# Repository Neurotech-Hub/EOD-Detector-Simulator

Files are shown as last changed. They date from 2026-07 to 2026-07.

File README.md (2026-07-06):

# EOD Detector — ngspice Simulation

Simulate the EOD detector front-end in incremental **stages**, from sanity checks through passives and active blocks. Python generates waveforms, runs ngspice in batch CLI mode, parses results, and plots waveforms.

Shared models live in [`circuits/models/`](circuits/models/) (INA333, MCP6561 comparator, …).

## Prerequisites

### ngspice

```bash
brew install ngspice
ngspice -v
```

Or set `NGSPICE` to the full path of the binary if it is not on `PATH`.

### Python

```bash
python3 -m venv .venv
source .venv/bin/activate
pip install -e ".[dev]"
```

## Quick start

List stages:

```bash
python scripts/run_stage.py --list
```

Run the INA333 sanity check (regression baseline):

```bash
python scripts/run_stage.py --stage 00_sanity_ina333
python scripts/run_ina333.py                    # same stage (alias)
python scripts/run_stage.py --stage 00_sanity_ina333 --model ti
```

Run the MCP6561 comparator sanity check:

```bash
python scripts/run_stage.py --stage 00_sanity_mcp6561
```

Run the full KiCad schematic incrementally:

```bash
python scripts/run_stage.py --stage 01_passives --waveform rounded
python scripts/run_stage.py --stage 02_frontend --waveform rounded
python scripts/run_stage.py --stage 03_detector --waveform rounded
```

Outputs: `outputs/stages/<stage_id>/`

### Tuning GUI

Interactive local UI for stage selection, parameter tuning, and dual-axis plots:

```bash
pip install -e ".[dev]"   # includes dash
python scripts/run_gui.py
```

Opens `http://127.0.0.1:8050` with three analysis tabs (Electrodes/ELEC_OUT, ELEC_OUT/COMP_IN, Comparator), overview vs single-pulse zoom, and pulse rate in **kHz** (default 0.5 kHz). The Electrodes tab overlays the commanded stimulus (dashed) against the simulated electrode differential so numerical problems are immediately visible.

### Options

```bash
python scripts/run_stage.py --stage 00_sanity_ina333 --gain 100 --pulse-mv 1.0 --plot plotly
python scripts/run_stage.py --stage 00_sanity_ina333 --waveform rounded --pulse-width-us 200
```

Single-pulse zoom (dual y-axis) is generated automatically for EOD input stages. The GUI always zooms the **first pulse** in the train.

```
outputs/stages/00_sanity_ina333/00_sanity_ina333_pulse1_ideal.png
```

| Flag | Default | Description |
|---|---|---|
| `--stage` | `00_sanity_ina333` | Simulation stage id |
| `--model` | (stage default) | Bench variant: `ideal`, `ti`, or `default` |
| `--gain` | 100 | INA333 gain (sets RG = 100k / (G - 1)) |
| `--pulse-mv` | 1.0 | Peak differential pulse amplitude (mV) |
| `--waveform` | square | Pulse shape: `square` (ideal) or `rounded` (smooth lobes) |
| `--pulse-width-us` | 200 | Total biphasic width for rounded waveform (µs) |
| `--sample-us` | auto | Waveform + `.tran` step (µs): 1 rounded, 10 square |
| `--no-pulse-zoom` | off | Skip single-pulse dual-axis plot (CLI only) |
| `--isi-ms` | 20 | Inter-pulse interval (ms) |
| `--num-pulses` | 4 | Number of pulses in the train |
| `--plot` | matplotlib | `matplotlib` or `plotly` |
| `--duration-ms` | 100 | Simulation duration (ms) |
| `--vref` | stage default | Reference voltage (V); 1.65 for KiCad stages |
| `--vthresh` | 1.85 | Comparator threshold (V) for stage 03 |
| `--vdd` | stage default | Supply voltage (V); 3.3 for KiCad stages |
| `--lf-offset` | off | Add slow sinusoidal differential offset (water artifact) |
| `--lf-offset-mv` | 100 | Peak LF offset amplitude (mV) |
| `--lf-offset-center-hz` | 20 | LF offset center frequency (Hz) |
| `--lf-offset-span-hz` | 10 | Draw f uniformly in [center−span, center+span] |
| `--lf-offset-seed` | (random) | Optional RNG seed for reproducible f and phase |

### Slow LF offset (water recording)

Enable `--lf-offset` to superimpose a slow differential sine on the EOD pulse train. Each run draws frequency in **10–30 Hz** (20 ± 10 by default) and a random phase relative to the first pulse. Use this to validate the input high-pass network in `01_passives`: the differential corner is ~59 Hz (2.35 nF effective coupling into the ~950 kΩ R15/R6 load), so a 20 Hz offset is attenuated to roughly a third at the INA inputs. In **Overview** view you should see large slow swings at the electrodes with a visibly smaller residual at the INA inputs when the filter is working.

```bash
python scripts/run_stage.py --stage 01_passives --waveform rounded --lf-offset --lf-offset-mv 150 --duration-ms 50
```

The tuning GUI exposes the same controls under **Slow water offset (~20 Hz)** in the Waveform section.

### INA input network (stages 01–03)

Tune the symmetric INA333 input passive network. Values are SPICE literals applied to both legs (or the shared differential element). INA gain stays fixed at G=2 (RG = 100k).

| Flag | Default | Component |
|---|---|---|
| `--c-couple` | `4.7n` | Input coupling cap (C2, C3) |
| `--r-series` | `100k` | Series input resistor (R4, R7) |
| `--r-vref` | `10Meg` | VREF bias resistor (R6, R8) |
| `--r-diff` | `1Meg` | Differential input resistor (R15) |
| `--c-diff` | `330p` | Differential input capacitor (C4) |
| `--electrode-mismatch` | `0` | Electrode impedance mismatch (%) — see below |

```bash
python scripts/run_stage.py --stage 01_passives --waveform rounded --c-couple 10n --r-series 47k
```

The tuning GUI shows an **INA input network** panel for stages `01_passives`, `02_frontend`, and `03_detector`. Pair with `--lf-offset` and **Overview** view to validate HPF attenuation of slow water artifacts.

### Electrode impedance mismatch (stages 01–03)

`--electrode-mismatch <pct>` (GUI: **Electrode mismatch (%)** in the INA
input network panel) inserts a per-electrode source resistance between the
stimulus and `ELEC_A`/`ELEC_B`:

- **0 (default):** ideal stiff drive (1 mΩ) — identical to the previous
  behavior.
- **m > 0:** enables the electrode model with nominal Rs = **15 kΩ** (fine
  Ag wire, ~5 mm exposed, fresh water — see
  [ELECTRODES.md](ELECTRODES.md)), split ±m/2 between the two electrodes:
  `R_ELEC_A = 15k·(1 + m/200)`, `R_ELEC_B = 15k·(1 − m/200)`.

This demonstrates the two in-band electrode effects from ELECTRODES.md
within the current differential-stimulus architecture: **amplitude droop**
(Rs against C4 forms a ~16 kHz corner at stock values) and **one-sided
biphasic distortion** (unequal Rs against the C2/R4 vs C3/R7 legs skews the
two lobes). With mismatch on, the dashed "Commanded stimulus (ideal)"
overlay in the Electrodes tab visibly departs from the simulated electrode
differential — physically this time, not numerically.

```bash
python scripts/run_stage.py --stage 01_passives --waveform rounded --pulse-mv 300 --electrode-mismatch 20
```

### Comparator network (stages 02–03)

Tune output coupling and hysteresis between INA output and comparator input.

| Flag | Default | Component |
|---|---|---|
| `--c-out` | `2.2n` | Output coupling cap (C5, VREF–ELEC_OUT) |
| `--r-comp` | `4.7k` | Series resistor ELEC_OUT–COMP_IN (R9) |
| `--r-hyst` | `1Meg` | Hysteresis resistor COMP_IN–TRIGGER (R5, stage 03 only) |

The tuning GUI shows a **Comparator network** panel for `02_frontend` and `03_detector`. R5 only applies to `03_detector` — stage 02 has no comparator, so it does not exist there.

Stage 03's comparator is a **behavioral MCP6561 equivalent** ([`eod_comparator_behavioral.inc`](circuits/stages/includes/eod_comparator_behavioral.inc)): threshold comparison against `VTHRESH`, rail-to-rail push-pull output, and hysteresis produced by the **physical R5/R9 network** exactly as on the board (TRIGGER swing through R5 shifts COMP_IN by ~`VDD·R9/(R9+R5)` ≈ 15 mV at the 4.7k/1Meg defaults). The Microchip vendor macromodel was retired from transient benches — see *Known limitations* below.

## Simulation validation

Every run is validated after ngspice completes; a run only counts as
successful when all checks pass. Otherwise the CLI/GUI reports an explicit
error instead of plotting misleading data.

- ngspice output is scanned for `timestep too small` / aborted-transient
  messages even when the exit code is 0.
- ngspice is killed after a **5-minute timeout** — a convergence-stuck run
  raises a clear error instead of hanging indefinitely.
- The raw file must span the full requested duration, be strictly
  monotonic in time, dense enough to trust, and free of NaN/Inf.
- **Stimulus fidelity:** the differential at the filesource nodes
  (`SRC_A − SRC_B`, upstream of the electrode model) is compared against
  the commanded waveform; any deviation above 1 mV fails the run. The
  filesource is stiff, so deviations indicate solver failure — while
  `ELEC_A/ELEC_B` may legitimately deviate when electrode mismatch is
  enabled.
- The GUI overlays the **commanded stimulus (ideal)** as a dashed trace on
  the Electrodes tab, keeps the previous good result when a run fails, and
  shows amber warnings from the quality checks.

## Board mapping (EOD_Detector_v3-1, value changes only)

Every tunable in this tool maps 1:1 onto a component on the fixed v3-1
topology, so explored values transfer straight back to the PCB:

| Sim parameter / flag | Board designator | Stock value |
|---|---|---|
| `--c-couple` | C2, C3 | 4.7 nF |
| `--r-series` | R4, R7 | 100 kΩ |
| `--r-vref` | R6, R8 | 10 MΩ |
| `--r-diff` | R15 | 1 MΩ |
| `--c-diff` | C4 | 330 pF |
| `--gain` (sets RG) | R3 | 100 kΩ (G = 2) |
| `--c-out` | C5 | 2.2 nF |
| `--r-comp` | R9 | 4.7 kΩ |
| `--r-hyst` | R5 | 1 MΩ |
| `--vthresh` | RV1 wiper (R13 = 5.1 kΩ, R17 = 330 Ω divider) | 1.85 V default |
| `--electrode-mismatch` | (environment: the electrodes/water, not a PCB part) | 0 % (model off) |

The monostable network (R11/C6 pulse width, R14/C9, LEDs) is downstream of
TRIGGER and not simulated.

## Suggested component values (sim-derived)

From deterministic sweeps with 200 µs rounded biphasic pulses at 0.5 kHz
(standard E-series values; all within the fixed v3-1 topology):

| Designator | Stock | Suggestion | Why (measured in sim) |
|---|---|---|---|
| **C4** | 330 pF | **47 pF — do not go lower** | Biggest win. Against the ~166 kΩ differential source impedance (2·R4 ∥ R15), 330 pF puts the low-pass corner at ~3 kHz — inside the EOD band. A 200 µs pulse keeps only 47% of its peak (32% at 100 µs). 47 pF moves the corner to ~20 kHz: 78% / 73% preserved. **Below ~43 pF the front end self-oscillates at ~48 kHz with stock C5** — see [C4_STABILITY.md](C4_STABILITY.md). |
| **R3** | 100 kΩ (G=2) | **51 kΩ (G≈3)** | At VTHRESH = 1.85 V, G=2 needs ≥300 mV pulses to trigger; G=3 detects 200 mV, and 100 mV once C4 = 47 pF. G=5 (RG = 24 kΩ) detects 100 mV even with stock C4 but eats headroom on large pulses. |
| **C2, C3** | 4.7 nF | keep, or **2.2 nF** if slow drift dominates | 2.2 nF halves the 20–30 Hz bleed-through at the INA inputs (16% vs 32% residual) for only ~6% pulse-peak loss. Keep 4.7 nF if drift is not a problem in practice. |
| **R9** | 4.7 kΩ | keep | COMP_IN tracks ELEC_OUT faithfully across the R9 sweep (200 Ω – 4.7 kΩ all converge and trigger cleanly). No measured benefit to changing. |
| **C5** | 2.2 nF | **remove** (or ≤ 470 pF) | 2.2 nF directly loads the INA333 output and forms an under-damped resonance; the front end self-oscillates and TRIGGER chatters continuously — the "stuck on" signature. **Bench-confirmed:** ~80 kHz, ~220 mV pk-pk ring at ELEC_OUT, eliminated by removing C5. Detection is identical without it (C4 + amp bandwidth already band-limit the path); 470 pF C0G is acceptable as EMI insurance. Details: [C4_STABILITY.md](C4_STABILITY.md). |
| **R5** | 1 MΩ | keep | Gives a ~15 mV hysteresis band: exactly one TRIGGER edge per pulse, no chatter, in every test. Going much smaller backfires — at 100 kΩ the R5 loading divides COMP_IN enough to raise the effective threshold and detection stops entirely. |
| **RV1** (VTHRESH) | ~1.85 V | keep as trim | Margin table: at G=3 with C4 = 47 pF, 100 mV pulses clear 1.85 V. Trim down for weaker signals, up to reject noise. |

Caveats, stated plainly:

- These sweeps optimize **pulse fidelity, slow-drift rejection, and
  threshold margin** against the commanded differential stimulus. Resistive
  **electrode impedance mismatch** can now be enabled
  (`--electrode-mismatch`), but **polarization (double-layer C), half-cell
  drift, and common-mode pickup are still not modeled** (see Deferred
  below), so treat those aspects as unverified by simulation.
- Combined check: with 100 mV LF drift superimposed on 300 mV pulse trains,
  both stock and suggested values produce exactly one trigger per pulse
  with zero drift-induced extras.

## Known limitations and sim-only elements

| Element | Physical? | Notes |
|---|---|---|
| Behavioral comparator (stage 03) | Equivalent | Reproduces the MCP6561's threshold, rail-to-rail output, and R5/R9 hysteresis; omits input bias/offset details and exact ~50 ns propagation delay (negligible vs 200–1000 µs EODs). |
| MCP6561 vendor macromodel | Retired for transient | Its ESD clamp diodes collapse the ngspice timestep **non-deterministically** when cascaded with the INA333 macromodel; solver sweeps (`sparse`, `rshunt`, `trap`, `itl4`, `cshunt`) either failed or distorted TRIGGER. Still used in the standalone `00_sanity_mcp6561` stage. |
| `Rload_amp` 1 MΩ (ELEC_OUT–VREF) | Bench load | Stabilizes the INA output in simulation. |
| `Rload_comp` 10 kΩ (TRIGGER–GND) | Bench load | Conventional comparator output load. |
| Ideal `VREF` source | Simplified | OPA333 reference buffer omitted ([stage 03 README](circuits/stages/03_detector/README.md)). |
| Ideal `VTHRESH` source | Simplified | RV1 potentiometer divider replaced by a fixed source (`--vthresh`); keep suggested thresholds within RV1's achievable range. |
| `sim_ti_transient.inc` options | Solver tuning | `method=gear`, relaxed tolerances, `TMAX=10u` for the TI INA333 macromodel. |
| XSPICE `filesource` stimulus | Sim input | Stiff voltage source pair on SRC_A/SRC_B; cannot be loaded by the circuit. `R_ELEC_A/B` (electrode mismatch model) sit between the source and ELEC_A/ELEC_B. |

### Deferred: electrode polarization and common-mode (CM-to-DM) modeling

**Resistive electrode mismatch is now modeled** via
`--electrode-mismatch` / the GUI's Electrode mismatch (%) control (per-
electrode series Rs = 15 kΩ ± m/2 between the source and
`ELEC_A/ELEC_B`). Still deferred: **electrode polarization (double-layer
capacitance), half-cell potential drift, and a separate common-mode /
gradient source for CM-to-DM conversion** — the remaining suspects for the
real-world continuous triggering issue. Design notes for bare Ag vs
Ag/AgCl and what to model next: [ELECTRODES.md](ELECTRODES.md).

### Detector convergence

With the behavioral comparator, the full R9 × pulse-shape matrix (200 Ω to
4.7 kΩ, rounded and square) converges deterministically in seconds — verified
by `pytest -m integration`. Any failure is loud: output scanning, post-run
validation, and a 5-minute ngspice timeout guarantee no silent partial plots.

## Project layout

```
circuits/
├── models/              Shared subcircuits (INA333, MCP6561, …)
└── stages/              Incremental simulation stages
    ├── README.md        Stage progression and how to add stages
    ├── 00_sanity_ina333/   INA333-only regression bench
    ├── 00_sanity_mcp6561/  MCP6561 comparator threshold step
    ├── 01_passives/        Electrode coupling + INA bias network
    ├── 02_frontend/          INA333 (G=2) + output filter
    ├── 03_detector/          Full front-end + behavioral comparator
    ├── includes/             Shared netlist fragments
    └── _template/          Copy to start a new stage

src/eod_sim/
├── stages/registry.py   Stage definitions (register new stages here)
├── runner.py            Shared generate -> simulate -> plot pipeline
├── waveforms.py         EOD pulse train generation
├── ngspice.py           Batch CLI runner and netlist patching
├── results.py           Raw file parsing
└── plot.py              Matplotlib / Plotly plots

scripts/
├── run_stage.py         Main CLI for any stage
└── run_ina333.py        Alias for sanity stage

outputs/stages/<stage_id>/   Generated artifacts (gitignored)
tests/                       Unit tests
```

## Adding a stage

1. Create `circuits/stages/NN_name/` with bench netlist(s) — see [`circuits/stages/_template/`](circuits/stages/_template/)
2. Register in [`src/eod_sim/stages/registry.py`](src/eod_sim/stages/registry.py) with `status="active"`
3. Run: `python scripts/run_stage.py --stage NN_name`

Full checklist: [`circuits/stages/README.md`](circuits/stages/README.md)

## TI vendor model

The TI macromodel is at [`circuits/models/ina333_ti.lib`](circuits/models/ina333_ti.lib). Use `--model ti` on the sanity stage. See [`circuits/models/TI_MODEL.md`](circuits/models/TI_MODEL.md).

## Tests

```bash
pytest                    # fast unit tests
pytest -m integration     # end-to-end ngspice runs (slow; requires ngspice)
```

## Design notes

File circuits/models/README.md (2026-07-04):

# Shared SPICE models

Reusable subcircuits and vendor macromodels for all simulation stages.

| Model | File | Wrapper | Docs |
|---|---|---|---|
| INA333 ideal | [`ina333_ideal.sub`](ina333_ideal.sub) | `INA333_IDEAL` | — |
| INA333 TI | [`ina333_ti.lib`](ina333_ti.lib) | `INA333` | [`TI_MODEL.md`](TI_MODEL.md) |
| MCP6561 comparator | [`mcp6561.lib`](mcp6561.lib) | `MCP6561` | [`MCP6561.md`](MCP6561.md) |

Include from stage netlists with a path relative to the stage folder:

```spice
.include "../../models/mcp6561.lib"
```

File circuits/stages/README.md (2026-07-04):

# Circuit stages

Simulations are organized as numbered **stages** — incremental slices of the real EOD detector schematic.

## Progression

| Stage | Folder | Status | Description |
|---|---|---|---|
| 00 | [`00_sanity_ina333/`](00_sanity_ina333/) | active | INA333 only — regression / sanity check |
| 00 | [`00_sanity_mcp6561/`](00_sanity_mcp6561/) | active | MCP6561 comparator threshold step |
| 01 | [`01_passives/`](01_passives/) | active | Electrode coupling + INA bias network |
| 02 | [`02_frontend/`](02_frontend/) | active | Passives + INA333 (G=2) + output filter |
| 03 | [`03_detector/`](03_detector/) | active | Full front-end + MCP6561 comparator |

Shared netlist fragments: [`includes/`](includes/)

Run any active stage:

```bash
python scripts/run_stage.py --list
python scripts/run_stage.py --stage 01_passives --waveform rounded
python scripts/run_stage.py --stage 02_frontend --waveform rounded
python scripts/run_stage.py --stage 03_detector --waveform rounded
```

Outputs land in `outputs/stages/<stage_id>/`.

## Shared resources

- **`circuits/models/`** — Reusable subcircuits and vendor models (INA333, MCP6561, …). See [`models/README.md`](../models/README.md).
- **`circuits/stages/includes/`** — Shared netlist fragments from KiCad schematic
- **`circuits/stages/_template/`** — Copy to start a new stage

## Adding a stage

1. Create `circuits/stages/NN_name/` with `README.md` and bench netlist(s)
2. Use `.include "../includes/..."` for shared fragments
3. Use `file="input_diff.txt"` in filesource blocks (patched at run time)
4. Add an entry to `src/eod_sim/stages/registry.py`
5. Run and commit

See [`_template/README.md`](_template/README.md) for a checklist.

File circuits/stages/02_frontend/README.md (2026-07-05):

# Stage 02 — INA333 front-end

Full input network plus INA333 (U6, RG = 100 kΩ → G = 2 V/V) and output coupling (C5, R9) to the comparator input node. The hysteresis resistor R5 and the MCP6561 are not populated in this stage — COMP_IN is observed open-circuit (high-impedance), as a scope probe would see it. TRIGGER does not exist here.

## Run

```bash
python scripts/run_stage.py --stage 02_frontend --waveform rounded
python scripts/run_stage.py --stage 02_frontend --model ti --waveform rounded
```

## Expected

- Measured gain at ELEC_OUT ≈ 2 V/V
- Pulse zoom: INA input diff vs ELEC_OUT − VREF

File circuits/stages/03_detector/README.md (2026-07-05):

# Stage 03 — Full detector

Complete KiCad front-end: passives, INA333 (G=2), output filter, and a behavioral MCP6561 comparator equivalent with fixed threshold.

## Simplifications

- OPA333 reference buffer → ideal `VREF = 1.65 V`
- RV1 potentiometer divider (R13/R17) → fixed `VTHRESH = 1.85 V` (tune with `--vthresh`)
- MCP6561 → behavioral comparator (`eod_comparator_behavioral.inc`): threshold comparison, rail-to-rail push-pull output, and hysteresis from the physical R5/R9 network

## Run

```bash
python scripts/run_stage.py --stage 03_detector --waveform rounded
python scripts/run_stage.py --stage 03_detector --model ti --waveform rounded
python scripts/run_stage.py --stage 03_detector --waveform rounded --vthresh 1.70 --pulse-mv 50
```

## Benches

Both variants use the behavioral comparator (`eod_comparator_behavioral.inc`) and converge deterministically:

- `ideal` — ideal INA333 model
- `ti` — TI INA333 vendor macromodel with relaxed transient options (`sim_ti_transient.inc`)

The Microchip MCP6561 macromodel was **retired from these benches**: its ESD clamp diodes collapsed the ngspice timestep non-deterministically when cascaded with the INA333 macromodel (see [MCP6561.md](../../models/MCP6561.md)). Hysteresis behavior is unchanged — it comes from the physical R5/R9 network, which is fully modeled.

## Notes

With G=2, a 1 mV EOD produces ~2 mV at ELEC_OUT. The default threshold (1.85 V) is ~200 mV above the 1.65 V reference — a 1 mV pulse will **not** trigger the comparator. Increase `--pulse-mv` or lower `--vthresh` to explore detection.

## Expected

- Comparator output toggles between ~0 V and ~3.3 V when COMP_IN crosses VTHRESH

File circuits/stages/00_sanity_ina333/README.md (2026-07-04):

# Stage 00 — INA333 sanity check

Baseline test bench: INA333 only, EOD-like differential pulse input, no additional passives.

Use this stage to verify ngspice, waveform generation, and gain after any toolchain or model changes.

## Benches

| File | Model |
|---|---|
| `bench_ideal.cir` | Ideal 3-op-amp INA333 |
| `bench_ti.cir` | TI macromodel (`circuits/models/ina333_ti.lib`) |

## Run

```bash
python scripts/run_stage.py --stage 00_sanity_ina333
python scripts/run_ina333.py                    # same stage (alias)
python scripts/run_stage.py --stage 00_sanity_ina333 --model ti
```

## Expected

At gain=100 and 1 mV differential pulses, measured gain should be ~100 V/V (ideal) or ~101 V/V (TI).

## Outputs

| Artifact | Description |
|---|---|
| `00_sanity_ina333_waveforms_<bench>.png` | Full train overview |
| `00_sanity_ina333_pulse1_<bench>.png` | Single-pulse zoom: Vin diff (left) vs Vout−REF (right) |

Use `--waveform rounded --sample-us 1` for analog dynamics. Adjust zoom with `--pulse-index` and `--pulse-margin-us`.

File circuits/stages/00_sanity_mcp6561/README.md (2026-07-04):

# Stage 00 — MCP6561 sanity check

Comparator threshold crossing with a PWL step on IN+ against a fixed 2.5 V reference on IN-.

## Expected behavior

| Time | IN+ | IN- | OUT (5 V supply) |
|---|-----|-----|---|
| < 1 ms | 1.0 V | 2.5 V | Low (~0 V) |
| > 1 ms | 3.0 V | 2.5 V | High (~5 V) |

## Run

```bash
python scripts/run_stage.py --stage 00_sanity_mcp6561
```

## Model

Uses [`circuits/models/mcp6561.lib`](../../models/mcp6561.lib). Connect VDD to top-level node `3` (ngspice vendor-model quirk — see [`MCP6561.md`](../../models/MCP6561.md)).

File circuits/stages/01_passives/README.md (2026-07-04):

# Stage 01 — Input passives

Electrode coupling (4.7 nF + 100 kΩ), INA bias resistors (10 MΩ to VREF), and differential network (R15, C4).

No active devices — validates HPF response and DC bias at INA inputs.

## Run

```bash
python scripts/run_stage.py --stage 01_passives --waveform rounded
```

## Expected

- INA+ / INA− DC bias ≈ 1.65 V (VREF)
- Differential pulse appears at INA inputs after coupling caps charge
- Overview: electrode diff (top) vs INA input diff (bottom)

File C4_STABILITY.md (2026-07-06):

# C4 stability sweep — front-end oscillation below ~43 pF

**TL;DR:** With the stock output network (C5 = 2.2 nF), the TI INA333 front
end becomes a self-sustaining **~48 kHz oscillator** when C4 drops below
~40 pF. The boundary is sharp (43 pF clean / 39 pF oscillates), it does
**not** require the comparator, and once started it never stops — TRIGGER
chatters rail-to-rail at ~47 kHz indefinitely, which at the monostable/LED
looks exactly like **"comparator stuck on."** Reducing **C5 to ≤ 1 nF
(470 pF recommended)** removes the oscillation entirely and makes C4 a free
choice. Keep **C4 = 47 pF** per the README recommendation, but treat it as
sitting at the edge of the stability region, not just a bandwidth choice.

Context: observed as "strong ringing" in the simulator for C4 < 47 pF, and suspected as a contributor to the continuous-trigger behavior seen in the tank. All sweeps: 300 mV rounded biphasic pulses (200 µs), 0.5 kHz, 4 pulses over 20 ms, stock values unless noted, TI bench.

## Symptom and evidence

From the run that prompted this (stage 03 TI, C4 = 22 pF, otherwise stock):

- First TRIGGER edge at 5.016 ms (first pulse), then **677 rising edges**
at a steady ~~47/ms until the end of the simulation — long after the last
pulse (~~11 ms). Self-sustaining, not per-pulse ringing.
- In a stimulus-free window (15–16 ms): `INA_P`/`INA_N` flat to **0.03 mV**,
while `ELEC_OUT`/`COMP_IN` swing **~0.77 V pk-pk at 47.5 kHz** and
TRIGGER swings rail-to-rail.
- The waveform is smooth over 10–20 solver points per cycle; where the
circuit is not oscillating the baseline is quiet to nanovolts.

**Not a solver artifact.** The oscillating stage-02 case (C4 = 33 pF) was
re-run with strict settings (`trtol=1 reltol=1e-4 abstol=1e-10 method=trap`,
61k timepoints) in place of the relaxed TI options: identical behavior
(0.88 V pk-pk at 48 kHz).

## Sweep results

### C4 boundary (stage 03 TI, C5 = 2.2 nF, R5 = 1 MΩ, rounded pulses)

| C4 | Gain 2 | Gain 3 |
| --- | --- | --- |
| 330 pF (stock) | clean (4 edges) | clean |
| 100 pF | clean | clean |
| 68 pF | clean | clean |
| **47 pF** | **clean** | **clean**  |
| **43 pF** | **clean** | — |
| **39 pF** | **oscillates** (~48 kHz) | — |
| 33 pF | oscillates | oscillates |
| 22 pF | oscillates | oscillates |
| 10 pF | oscillates | oscillates |

The boundary (between 43 and 39 pF) is essentially independent of gain.

### Controls — what the oscillator is and isn't

| Experiment | Result | Conclusion |
| --- | --- | --- |
| Stage 03 **ideal** bench, C4 = 22 pF / 10 pF | clean | The ideal INA (pure gain block) never oscillates → the TI INA333 macromodel's dynamics are the resonant element.  |
| Stage 02 (**no comparator**), C4 = 39/33/22 pF | sustained ~754 mV pk-pk at ELEC_OUT | The comparator is **not required** — the INA + C5 output load self-oscillates. The comparator only reports it. |
| Stage 02, C4 = 330 pF | 3.3 mV ring decaying to 0.05 mV after each pulse | The under-damped resonance exists at stock values too; large C4 keeps it damped. |
| Stage 03 TI, C4 = 22 pF, R5 = 470k/330k/220k | all oscillate | More hysteresis does **not** fix it (consistent with the comparator not being in the loop). |
| **Square** pulses, gain 2 | 100 pF clean; **68 pF and 47 pF oscillate** | Faster edges shift the boundary up — the margin at 47 pF depends on the input being band-limited (real EODs are). |

### Mitigation — C5 (stage 03 TI, C4 = 22 pF, rounded)

| C5 | Result |
| --- | --- |
| 2.2 nF (stock) | oscillates (~48 kHz) |
| **1 nF** | **clean** |
| **470 pF** | **clean** |
| 220 pF | clean |
| 100 pF | clean |

With C5 = 470 pF the front end is clean for **every C4 tested down to
4.7 pF** (gain 3), and the recommended combo passes even the square-pulse
stress test:

| Configuration (gain 3) | Result |
| --- | --- |
| Stock: C4 = 330 pF, C5 = 2.2 nF | clean, measured gain 3.00 |
| README rec: C4 = 47 pF, C5 = 2.2 nF | clean, gain 3.01 |
| **Combo: C4 = 47 pF, C5 = 470 pF**  | **clean, gain 3.00 — clean on square pulses too** |

## Mechanism (what the data supports)

- The INA333 is a 350 kHz-GBW, ~0.16 V/µs micro-power amplifier whose
closed-loop output impedance rises with frequency. **C5 = 2.2 nF sits
directly on its output** (to VREF), forming an under-damped resonance in
the tens-of-kHz range — visible as a small decaying ring even at stock
values. Real amplifiers of this class genuinely misbehave with nF-scale
direct capacitive loads.
- C4 (against the ~166 kΩ differential source impedance, 2·R4 ∥ R15)
band-limits what reaches the amplifier. Below ~40 pF the amplified pulse
edge is fast enough to drive the output stage into a large-signal,
slew-limited oscillation against C5 that never damps out.
- The oscillation loop is confined to the amplifier + its output load: the
INA inputs stay flat while it runs, the ideal-INA bench is immune, and
removing the comparator changes nothing.

## Bench confirmation (Jul 2026)

The predicted oscillation was observed directly on hardware: with
C5 = 2.2 nF and R9 = 10 kΩ (R5 = 1 MΩ), ELEC_OUT showed a sustained
**~80 kHz, ~220 mV pk-pk ring**; **removing C5 eliminated it entirely.**
This is the mechanism above, not the comparator — the sim reproduces the
oscillation in stage 02 with no comparator populated at all. The
frequency shift (sim ~48 kHz → bench ~80 kHz) is expected per the caveats:
the resonance is set by the real part's closed-loop output impedance,
which the TI macromodel only approximates.

Note that **R9 does not protect the amplifier**: C5 is a *shunt* from
ELEC_OUT to VREF, directly on U6's output, upstream of R9. Raising R9
changes the hysteresis divider but leaves the amp facing the full C5.

Follow-up sims with **C5 removed** (open) at R9 = 10 kΩ: detection is
identical to C5 = 470 pF in every case tested — 4 clean TRIGGER edges for
rounded and square 300 mV pulses and for near-threshold 120 mV pulses.
C5 contributes nothing measurable to detection; the signal is already
band-limited by C4 (~20 kHz) and the INA's closed-loop bandwidth
(~115 kHz at G = 3), and chatter immunity comes from the R5/R9
hysteresis, not from C5. **Revised recommendation: delete C5, or keep at
most 470 pF (C0G) as EMI insurance.**

## Tank relevance ("comparator stuck on")

Bench tests with **C4 absent** (populated footprint, no cap) reproduced the
same ringing / stuck-on behavior. In the GUI, **Component defaults →
Detector v3 - No C4** models this with C4 = 1 fF (effectively open between
INA+ and INA−); all other values match the KiCad v3 stock network.

A TRIGGER pin oscillating at ~47 kHz continuously retriggers the
monostable and looks exactly like a stuck-on detector. Two reasons the real
board may be **more** susceptible than the sim:

1. **VREF is ideal in simulation.** On the PCB, C5's resonant current is
  dumped into the OPA333 VREF buffer; VREF bounce couples into the input
   bias network (R6/R8), the INA REF pin, and the RV1 threshold divider —
   feedback paths the sim does not represent.
2. **Electrode source impedance** (now modeled via `--electrode-mismatch`)
  raises the differential source impedance and shifts the input corner,
   moving the effective boundary around in the field.

## Recommendations

1. **Never go below C4 = 47 pF** with the stock output network. The
  simulated boundary is 43→39 pF for rounded 200 µs pulses, and moves up
   to ~68–100 pF for fast-edged (square) inputs — 47 pF has thin margin.
2. **Delete C5, or keep at most 470 pF (C0G).** Bench-confirmed: removing
   C5 eliminates the oscillation, and sims show detection is identical
   with C5 open vs 470 pF (rounded, square, and near-threshold pulses).
   Its intended filtering is redundant (C4 + amp bandwidth already
   band-limit the path) and it sits on the wrong side of R9 to protect
   COMP_IN. Never populate nF-scale values here.
3. Recommended combo, superseding the "keep C5" line in the README's
   suggested-values table: **gain ≈ 3 (R3 = 51 kΩ), C4 = 47 pF,
   C5 removed (or ≤ 470 pF)**, R5/R9 stock. R5 is not a lever here —
   extra hysteresis does not stop the oscillation. R9 stays regardless:
   it forms the hysteresis divider with R5.
4. **Bench verification:** done — see *Bench confirmation* above. A
   series isolation resistor between U6's output and the C5 position
   remains the topology-level fix on a future board revision if a cap is
   ever wanted there.

## Caveats

- The exact boundary values come from the **TI INA333 macromodel**; its
output-impedance model sets the resonant frequency and damping, so trust
the mechanism and the ordering, not the picofarad. The qualitative
warning (nF-scale direct output load + wide input bandwidth =
under-damped front end) is consistent with known amplifier behavior.
- The behavioral comparator faithfully relays the oscillation but plays no
role in creating it (verified in stage 02).
- Sweeps used the stiff electrode drive. Electrode impedance
(`--electrode-mismatch`) adds source resistance that interacts with the
same corner — re-check margin when exploring electrode effects.

See also: [README](README.md) (suggested component values),
[ELECTRODES.md](ELECTRODES.md).

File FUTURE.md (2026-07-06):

# FUTURE — project intent, hardware review, and where to take it

A knowledge-capture document for the EOD Detector (v3-1): why it exists,
how the current hardware works part-by-part, what this simulation/bench
campaign taught us, and what would make the circuit more robust — biased
strongly toward **zero-or-minor changes to the existing PCB**.

See also: [README](README.md) (board map, suggested values),
[C4_STABILITY.md](C4_STABILITY.md) (oscillation sweep),
[ELECTRODES.md](ELECTRODES.md) (electrode physics).

## 1. Project intent

Detect the electric organ discharges (EODs) of weakly electric fish in
fresh water and emit a clean digital TRIGGER (plus LED indication) per
pulse. The device is a **battery-powered wearable**: fine silver wire
electrodes (~5 mm exposed, ~1 cm from the PCB) pick up the fish's
biphasic field pulses — roughly 100 µV to hundreds of mV differential,
200–1000 µs wide, at rates up to ~1 kHz — in an electrically hostile
environment (electrode drift, tank gradients, mains pickup).

The design constraints that shaped everything:

- **Micropower.** Every active part is chosen for µA-class quiescent
  current (INA333 ≈ 25 µA, MCP6561 ≈ 100 µA, OPA333 ≈ 17 µA typical).
  Total analog budget is well under 1 mA — weeks on a small cell.
- **Analog-only detection.** No MCU in the signal path: amplify, filter,
  compare, one-shot. Simple, deterministic, low power.
- **Fixed topology, tunable values.** The v3-1 PCB layout exists; this
  simulation stack exists precisely to find the best *component values*
  within that topology before touching copper.

The simulator's job: faithfully reproduce the physical dynamics of this
chain (validated against tank behavior), so value choices transfer
straight to the board.

## 2. Current hardware (v3-1), component by component

Signal path: electrodes → AC-coupled bias network → INA333 → output
filter → MCP6561 comparator → monostable/LED.

### Mid-rail reference (U1 OPA333 + R1/R2/R10/C19/C20)

| Part | Value | Purpose |
|---|---|---|
| R1, R2 | 1 MΩ each | Divide 3.3 V to 1.65 V mid-rail (only 1.65 µA burned) |
| C19 | 100 nF | Quiets the high-impedance divider node |
| U1 (OPA333) | — | Buffers the divider so VREF can source/sink current |
| R10 | 22 Ω | In the buffer's output/feedback network (per netlist, between VREF and U1−) — helps tolerate the capacitive load on VREF |
| C20 | 100 nF | Local VREF reservoir |

Single-supply operation requires everything to be biased around a
mid-rail "virtual ground." VREF feeds the input bias resistors, the INA
REF pin, C5's cold end, and the threshold divider — **which also makes it
a shared coupling path** (see §4).

### Input coupling and bias (C2/C3, R4/R7, R6/R8, R15, C4)

| Part | Value (stock) | Purpose |
|---|---|---|
| C2, C3 | 4.7 nF | AC-coupling: block electrode DC offset and half-cell drift; with the ~950 kΩ load they form the ~59 Hz differential high-pass |
| R4, R7 | 100 kΩ | Series isolation: limit input current, protect the INA, and (with C4) set the differential low-pass |
| R6, R8 | 10 MΩ | Bias the floating INA inputs to VREF without loading the signal (sets input common mode) |
| R15 | 1 MΩ | Differential termination: defines the differential source impedance seen by the INA (~166 kΩ with 2·R4 ∥ R15) |
| C4 | 330 pF | Differential low-pass with that source impedance; kills RF/EMI **and — as we learned — damps the front end** |

This passive network is the part we spent the campaign testing. Its two
corners bracket the EOD band: high-pass ~59 Hz (drift rejection),
low-pass ~3 kHz at stock C4 (which is actually *inside* the band —
motivating the C4 = 47 pF recommendation that moves it to ~20 kHz).

### Gain stage (U6 INA333 + R3)

R3 = RG sets gain: G = 1 + 100 kΩ/RG. Stock 100 kΩ → G = 2; recommended
51 kΩ → G ≈ 3. The INA333 gives high CMRR at µA supply current, but it's
a 350 kHz-GBW, 0.16 V/µs part — its output stage **cannot drive nF-scale
capacitance** gracefully, which is the root of the instability found in
this campaign.

### Output filter (C5, R9)

| Part | Value (stock) | Purpose |
|---|---|---|
| C5 | 2.2 nF | **Shunt** from ELEC_OUT to VREF — intended as a noise snubber on the comparator path |
| R9 | 4.7 kΩ | Series element into COMP_IN; with R5 sets the hysteresis divider |

C5 sits **directly on the INA output** (upstream of R9, so R9 cannot
isolate the amp from it) — the single most consequential placement on the
board (see §3). Bench + sim verdict: its filtering job is already done by
C4 and the amp's own bandwidth, so it should be deleted or kept ≤ 470 pF.

### Detection (U3 MCP6561, RV1 + R13/R17, R5)

| Part | Value | Purpose |
|---|---|---|
| R13/R17 + RV1 | 5.1 kΩ / 330 Ω + trimmer | Threshold divider: VTHRESH ≈ 1.85 V (~200 mV above VREF), field-adjustable |
| U3 (MCP6561) | — | Push-pull rail-to-rail comparator, ~100 µA |
| R5 | 1 MΩ | Positive feedback COMP_IN←TRIGGER: ~15 mV hysteresis band |

The R5/R9 hysteresis is physically correct on the board and in the sim
(the behavioral comparator model keeps it). ~15 mV gives exactly one
edge per pulse in every clean test; smaller R5 backfires by dividing
COMP_IN down and raising the effective threshold.

### Downstream (not simulated)

Monostable (R11/C6 pulse stretch, R14/C9) and LEDs. These only shape
TRIGGER for visibility; they faithfully relay whatever the comparator
does — including 47 kHz chatter.

## 3. What this build taught us

1. **The front end can self-oscillate, and it looks like "stuck on."**
   With stock C5 = 2.2 nF, dropping C4 below ~40 pF (or removing it —
   the bench condition that reproduced the tank failure) lets the INA
   output ring against C5 in a self-sustaining ~48 kHz oscillation.
   TRIGGER chatters rail-to-rail indefinitely. The comparator is
   innocent; the loop is entirely INA output ↔ C5.
2. **C4 is a stability component, not just a bandwidth trim.** Large C4
   band-limits the edges reaching the amplifier and keeps the resonance
   damped. That's why the board "worked" at 330 pF and failed with C4
   absent.
3. **C5 is not worth keeping — bench-confirmed.** With C5 = 2.2 nF
   (R9 = 10 kΩ) the bench showed a sustained ~80 kHz, ~220 mV pk-pk ring
   at ELEC_OUT; removing C5 eliminated it, matching the sim's predicted
   mechanism (sim frequency ~48 kHz — the difference is the macromodel's
   approximate output impedance). Sims with C5 open are identical to
   470 pF for detection (rounded, square, near-threshold). Its filtering
   is redundant: C4 (~20 kHz) and the INA's closed-loop bandwidth
   (~115 kHz at G = 3) already band-limit the path, and chatter immunity
   comes from R5/R9 hysteresis. Delete it, or keep ≤ 470 pF as EMI
   insurance. R9 stays — it is load-bearing for hysteresis.
4. **Detection margin wants G ≈ 3 and C4 = 47 pF.** At VTHRESH = 1.85 V:
   stock (G=2, C4=330p) needs ≥300 mV pulses; the recommended combo
   detects 100 mV pulses with in-band fidelity preserved (~78% of peak
   at 200 µs vs 47% stock).
5. **Electrodes are a first-class circuit element.** Each wire is
   ~15 kΩ of spreading resistance (Randles cell); *mismatch* between the
   two converts common-mode to differential and skews the biphasic
   lobes. Bare Ag drifts (mV over seconds–minutes); Ag/AgCl mostly fixes
   drift but not mismatch. Now partially modeled
   (`--electrode-mismatch`).
6. **The slow-drift path is under control.** The ~59 Hz input high-pass
   attenuates 20–30 Hz water artifacts to roughly a third at the INA
   inputs; no drift-induced false triggers in any combined test.
7. **VREF is a shared node.** In sim it is ideal; on the board, C5's
   current is dumped into the OPA333 buffer and can bounce the bias
   network, INA REF, and threshold divider together — one plausible
   reason the real board fails *more easily* than the sim.

## 4. Future enhancements

Ordered by invasiveness. Everything in tiers 1–2 uses jellybean 0402/0603
parts (C0G/NP0 ceramics, E24 1% resistors) available from any distributor.

### Tier 0 — value swaps only (do these)

| Change | From → To | Why |
|---|---|-----|
| **C5** | 2.2 nF → **removed** (or ≤ 470 pF C0G) | Bench-confirmed oscillator (80 kHz ring at ELEC_OUT; gone with C5 out). Detection is identical without it — its filtering is redundant. The single highest-value change on the board |
| **R3** | 100 kΩ → **51 kΩ** (G ≈ 3) | Detects 100 mV pulses at the stock threshold; keeps headroom |
| **C4** | 330 pF → **47 pF** (C0G) | Moves the in-band low-pass corner from ~3 kHz to ~20 kHz; preserves pulse fidelity. Safe *once C5 is removed/reduced*; never populate below 47 pF with stock C5, and never leave it off |
| C2, C3 | keep 4.7 nF (or 2.2 nF if drift dominates in practice) | 2.2 nF halves LF bleed-through for ~6% peak loss |
| R5, R9, RV1 | keep | Verified correct as-is; R9 is load-bearing for the R5/R9 hysteresis divider (R9 = 10 kΩ also fine — widens the band to ~33 mV) |

Use C0G/NP0 dielectric for C4 (and C5, if populated) — X7R at these small
values varies with bias and temperature, and C4 sits at a stability
boundary.

### Tier 1 — PCB hacks worth doing on existing boards

- **Series isolation resistor between U6 output and C5** (~100–330 Ω).
  The textbook fix for capacitive loading: it damps the resonance for
  *any* C5. Hack: lift C5's ELEC_OUT pad and bridge with an 0402
  resistor stacked on end. Only relevant if a cap is populated in the C5
  position at all (with C5 removed — the current recommendation — there
  is nothing to isolate). With R9 ≥ 10 kΩ downstream, the divider loss
  at COMP_IN is ≤ 3%.
- **Chloride the electrodes (Ag/AgCl).** Removes the dominant drift
  failure mode for the cost of a bleach dip or anodizing in KCl. Note
  the wearable caveat: thin AgCl layers deplete under sustained bias —
  soak-test before a long deployment.
- **Conformal-coat the input network.** R6/R8 are 10 MΩ; on a wearable
  in water, surface moisture leakage across those nodes rivals the
  intended bias currents. Acrylic or silicone coat over the C2–C4/R4–R8
  region (leave the electrode terminals exposed).
- **Add a scope point on ELEC_OUT** (wire to a via or pad) if not
  already accessible — the definitive stuck-on diagnostic is a
  tens-of-kHz oscillation there.

### Tier 2 — next board spin (same topology, minor edits)

- **Footprint for the U6-output series resistor** (0 Ω default). Free
  insurance, zero layout disruption.
- **Stiffen VREF locally**: bump C20 to 1 µF and verify R10 = 22 Ω
  against the OPA333's capacitive-load tolerance; consider separate RC
  decoupling for the threshold divider branch so comparator-side
  transients don't modulate VTHRESH through the shared node.
- **Tolerance-match the input pairs**: specify C2/C3 at ±5% (C0G) and
  R4/R7 at ±0.1% if available (0402 thin-film 0.1% 100 kΩ is a stocked
  part). Mismatch here converts common-mode to differential exactly like
  electrode mismatch does — it's the half of the CM→DM budget we control.
- **Guard ring or increased clearance** around the INA input nodes
  (10 MΩ bias) to reduce leakage sensitivity.
- **Test pads for electrode impedance measurement** (drive a small
  current, read voltage) so field units can verify electrode health.

### Tier 3 — directions we considered and deliberately deferred

- **MCU/DAC threshold, digital detection.** Contradicts the analog
  micropower intent; RV1 is adequate. Not recommended.
- **Higher-order filtering / active filters.** More op-amps, more µA,
  more instability surface. The passive corners are sufficient once C4
  and C5 are right.
- **Full Randles electrode modeling + common-mode source in sim.**
  Remaining work item (see ELECTRODES.md): per-electrode Rs ∥ (Cdl+Rct),
  drift source, and a CM/gradient source to produce a *tolerance budget*
  for mismatch × pickup. Do this pass before betting a long field
  deployment on threshold margins.
- **New amplifier.** The INA333's capacitive-load sensitivity is real
  but fully managed by C5/isolation-R. Any pin-compatible alternative
  with more drive costs supply current; not worth it.

## 5. Open questions

1. Does the bench show the predicted tens-of-kHz oscillation at U6's
   output during a stuck-on event? (Confirms the mechanism on hardware.)
2. Where does the real stability boundary sit with actual electrodes
   attached? (Electrode Rs interacts with the same input corner — re-run
   the C4 sweep with `--electrode-mismatch` once tank-validated.)
3. How fast do chlorided electrodes deplete in the wearable duty cycle?
   (Bench soak test, not SPICE.)
4. What is the actual CM pickup amplitude in the tank? One measurement
   would anchor the deferred CM→DM simulation pass.

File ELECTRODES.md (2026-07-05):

# Electrodes — notes for sim and bench

Context: fine **silver wire**, ~**5 mm exposed** to water, ~**1 cm** from PCB,
**fresh water** (~50–500 µS/cm). Fixed v3-1 topology; value changes only unless
noted.

## Bare Ag in freshwater (current)

Each electrode behaves roughly like a **Randles cell**:

| Element | Order of magnitude | Relevance at EOD rates (200–1000 µs) |
|---|---|---|
| **Rs** (spreading) | ~3–30 kΩ per wire (~15 kΩ nominal at ~100 µS/cm) | **Dominant** — each electrode ≈ a resistor in-band |
| **Cdl** (double layer) | ~0.5–1 µF | ~200 Ω at ~1 kHz — negligible vs 4.7 nF coupling (C2/C3) |
| **Rct** (charge transfer) | Very high (bare Ag, no stable couple) | Interface drifts; slow polarization |
| **Drift / offset** | Unstable half-cell, mV-scale wander over seconds–minutes | Prime suspect for **LF bleed-through** and **continuous triggering** |

**Rs sits in series with C4 (330 pF)** on the differential path → extra LPF corner
~Rs/(2·C4) ≈ **~16 kHz** with ~30 kΩ total Rs. Compounds the in-band C4 roll-off
already flagged in the README (C4 → **47 pF** recommendation still applies).

**What does *not* matter much:** INA bias current × Rs (~µV); Cdl on the HPF
(dominated by C2/C3).

## What actually drives field failures (bare or chlorided)

1. **Electrode + board mismatch → CM→DM conversion** — unequal Rs/Cdl/Rct, plus
   C2/C3 and R4/R7 tolerance. Tank gradients and mains couple in as
   **common-mode**; even 0.1–1% conversion can produce mV differential at the
   INA — enough to cross threshold intermittently.
2. **Slow drift / DC offset** — large for **bare Ag**; much smaller for **matched
   Ag/AgCl**.

**Now live in the sim:** the stimulus
(`circuits/stages/includes/eod_stimulus.inc`) drives stiff SRC_A/SRC_B
nodes through per-electrode series resistors `R_ELEC_A/B`. The
`--electrode-mismatch <pct>` flag (GUI: **Electrode mismatch (%)**) sets
Rs = **15 kΩ ± m/2** per electrode (0 = stiff drive, model off). This
captures the **resistive** effects above — in-band droop through C4 and
one-sided lobe skew from unequal Rs. Cdl/Rct, drift, and common-mode
pickup are still not represented (see below).

## Ag/AgCl wires — what changes

| | Bare Ag | Ag/AgCl |
|---|---|---|
| **Rct** | Very high | ~1–20 kΩ (reversible AgCl/Ag couple) |
| **Drift / polarization** | Large, unstable | Small stable half-cell (~tens of mV) |
| **Rs, Cdl** | Same (geometry + water) | Same |
| **Mismatch CM→DM** | Yes | **Still yes** — unequal chloriding, area, Rct; board tolerance unchanged |

Ag/AgCl removes the main **drift** failure mode but **not** mismatch or CM→DM.
Residual risk: **differential DC offset** between wires (tens of mV) eating
trigger margin (threshold ~200 mV above VREF at G≈3).

**Wearable caveat:** small chlorided wires **deplete AgCl** under sustained
DC/bias; behavior can revert toward bare Ag over long immersion — bench soak
test, not SPICE.

## Simulation — worth it or not?

- **Not worth chasing exact Rs/Cdl/Rct** — water chemistry and wire prep dominate
  uncertainty.
- **Worth one bounded pass:** mismatch × common-mode **margin** sweep, not “find
  the true Rs.”

**Done (first slice):** per-electrode series **Rs with mismatch %**
(`--electrode-mismatch`) is implemented — see README "Electrode impedance
mismatch."

Remaining for a future pass:

- Replace the differential-only source with **CM source + differential
  (fish) source** and extend each electrode to the full **Rs ∥ (Cdl +
  Rct)** Randles branch with **mismatch %** on Cdl/Rct too.
- **Bare Ag:** include slow drift source (mV, <1 Hz).
- **Ag/AgCl:** low Rct (~5 kΩ), **no large drift**; add small **Vhalf offset
  mismatch** (±25 mV swept).
- Sweep: mismatch 0–50%, CM amplitude; watch INA diff, COMP_IN, TRIGGER for
  false edges.

Output = **tolerance budget**, not a single “correct” electrode value.

## Practical recommendation

1. **Bench:** prefer **Ag/AgCl** (or chlorided silver) for stable LF behavior vs
   bare Ag in plain water.
2. **Component tuning:** proceed with README suggestions (**C4 = 47 pF**, **R3 →
   G≈3**, keep R5/R9/C5) — valid regardless of electrode chemistry for Rs.
3. **Sim next (optional but targeted):** one Ag/AgCl-oriented mismatch + CM sweep
   to confirm margin before long tank tests; skip full bare-Ag drift modeling if
   electrodes are chlorided.

See also: [README](README.md) (board map, suggested values, deferred modeling).

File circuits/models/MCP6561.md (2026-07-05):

# MCP6561 Comparator Model

Microchip rail-to-rail comparator macromodel for ngspice, vendored at [`mcp6561.lib`](mcp6561.lib).

**Source:** Microchip MCP6561 SPICE model (Rev B, 09-Apr-2011)  
**Covers:** MCP6561, MCP6561R, MCP6561U, MCP6562, MCP6564

## Pin order

Subcircuit `MCP6561`:

| Pin | Name |
|-----|---|
| 1 | IN+ (non-inverting) |
| 2 | IN- (inverting) |
| 3 | VDD |
| 4 | VSS |
| 5 | OUT |

Example instance:

```spice
.include "models/mcp6561.lib"
Vsupply 3 0 5
Vref in_n 0 2.5
Vin in_p 0 PWL(0 1.0 1m 1.0 1.001m 3.0 5m 3.0)
XU1 in_p in_n 3 0 out MCP6561
```

## ngspice quirk: VDD node must be named `3`

This vendor model only switches correctly when the **VDD pin connects to a top-level net named `3`**. Using `VDD`, `vsup`, or other supply net names causes the output to stick near 0 V.

Workaround in your netlist:

```spice
Vsupply 3 0 5
XU1 in_p in_n 3 0 out MCP6561
```

Probe other nodes with descriptive names (`in_p`, `in_n`, `out`) as usual.

## ngspice status

Runs in ngspice 46 on transient analysis without file edits. Verified:

```bash
python scripts/run_stage.py --stage 00_sanity_mcp6561
```

Expected: Vout ≈ 0 V when IN+ < IN−, Vout ≈ 5 V when IN+ > IN−.

### Retired from the detector transient benches (stage 03)

This vendor macromodel is **no longer used in the stage 03 detector benches**. Its ESD clamp diodes (`D98`/`D99`, `DESD` with `IS=1e-15`) collapse the ngspice timestep **non-deterministically** when cascaded with the INA333 macromodel — identical runs pass or fail at random with "timestep too small" at `d.xu3.d98`. Exhaustive solver sweeps (`method=gear`/`trap`, `sparse`, `rshunt`, `itl4`, `cshunt`, `TMAX`, parasitic caps) either failed to fix this or distorted TRIGGER (e.g. `cshunt=1p` caused −0.8/+4.1 V rail overshoot).

Stage 03 now uses a **behavioral equivalent** ([`eod_comparator_behavioral.inc`](../stages/includes/eod_comparator_behavioral.inc)): threshold comparison against VTHRESH, rail-to-rail push-pull output referenced to the supply, and hysteresis from the physical R5/R9 feedback network — the electrically relevant behavior for EOD detection, without the stiff ESD network. The vendor includes (`eod_comparator.inc`, `eod_comparator_ti.inc`) remain in the tree, marked deprecated for transient use.

The macromodel is still exercised standalone in the `00_sanity_mcp6561` stage, where it converges fine.

The INA333 TI library may emit harmless `t_abs` warnings on internal resistor models; ngspice ignores them.

## Usage notes (from Microchip)

- Typical performance over −40 °C to +125 °C
- For high-impedance circuits, consider `.options gmin=100f`
- Hysteresis disabled in our vendored copy (`E12` uses `POLY(6)` no-hysteresis line) for reliable ngspice convergence

## Sanity bench

See [`circuits/stages/00_sanity_mcp6561/`](../stages/00_sanity_mcp6561/).

## Updating the model

1. Replace `mcp6561.lib` with a new vendor download
2. Re-apply header comment and hysteresis patch (see top of file)
3. Re-run the sanity stage and confirm the node-`3` VDD workaround still applies

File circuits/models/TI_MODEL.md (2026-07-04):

# TI INA333 SPICE Model

The repo includes an ngspice-compatible copy of the TI macromodel at [`ina333_ti.lib`](ina333_ti.lib).

**Source:** Texas Instruments INA333 TINA-TI Spice Model (SBOM310E / INA333.LIB, Rev 1.2, Feb 2019)

## Usage

```bash
python scripts/run_ina333.py --model ti
python scripts/run_ina333.py --model ideal   # default, faster
```

Compare outputs side by side:

```bash
python scripts/run_ina333.py --model ideal
python scripts/run_ina333.py --model ti
# -> outputs/ina333_waveforms_ideal.png
# -> outputs/ina333_waveforms_ti.png
```

## ngspice patches applied

The vendor file required these changes to run in ngspice:

| Issue | Patch |
|---|---|
| `TEMP` in VOS drift expressions | Fixed at DC (27 °C nominal) |
| PSpice `IF()` | Ternary `? :` operator |
| PSpice `LIMIT()` | Nested ternary clamp |
| PSpice `VSWITCH` | ngspice `SW` (Vt/Vh from VON/VOFF) |

See the header comment in `ina333_ti.lib` for details.

## Pin order

TI subcircuit: `INA333 IN+ IN- VCC VEE OUT REF RG+ RG-`

Bench instance in [`circuits/stages/00_sanity_ina333/bench_ti.cir`](../stages/00_sanity_ina333/bench_ti.cir):

```spice
XU1 in_p in_n VDD 0 out REF RGp RGn INA333
```

## Gain = 1 note

Per TI forum guidance, for unity gain set RG to a very large value (e.g. 1 TΩ) rather than leaving RG pins open.

## Updating the model

To refresh from a new TI download:

1. Copy the vendor `INA333.LIB` to this directory
2. Re-apply the patches listed above (or diff against `ina333_ti.lib`)
3. Verify with `python scripts/run_ina333.py --model ti`

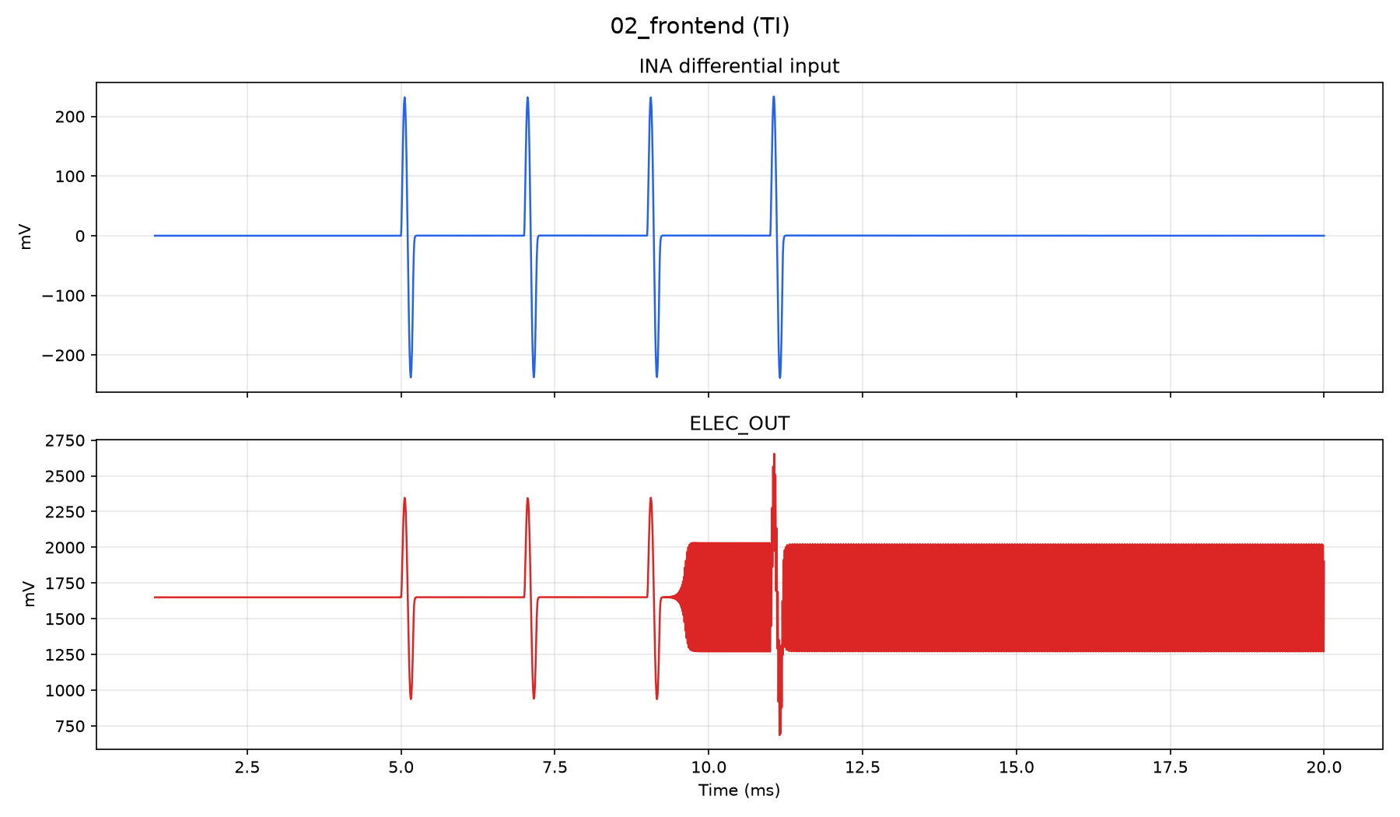
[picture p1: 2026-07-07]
outputs_probe/bench_s02_47p/stages/02_frontend/02_frontend_waveforms_ti.png

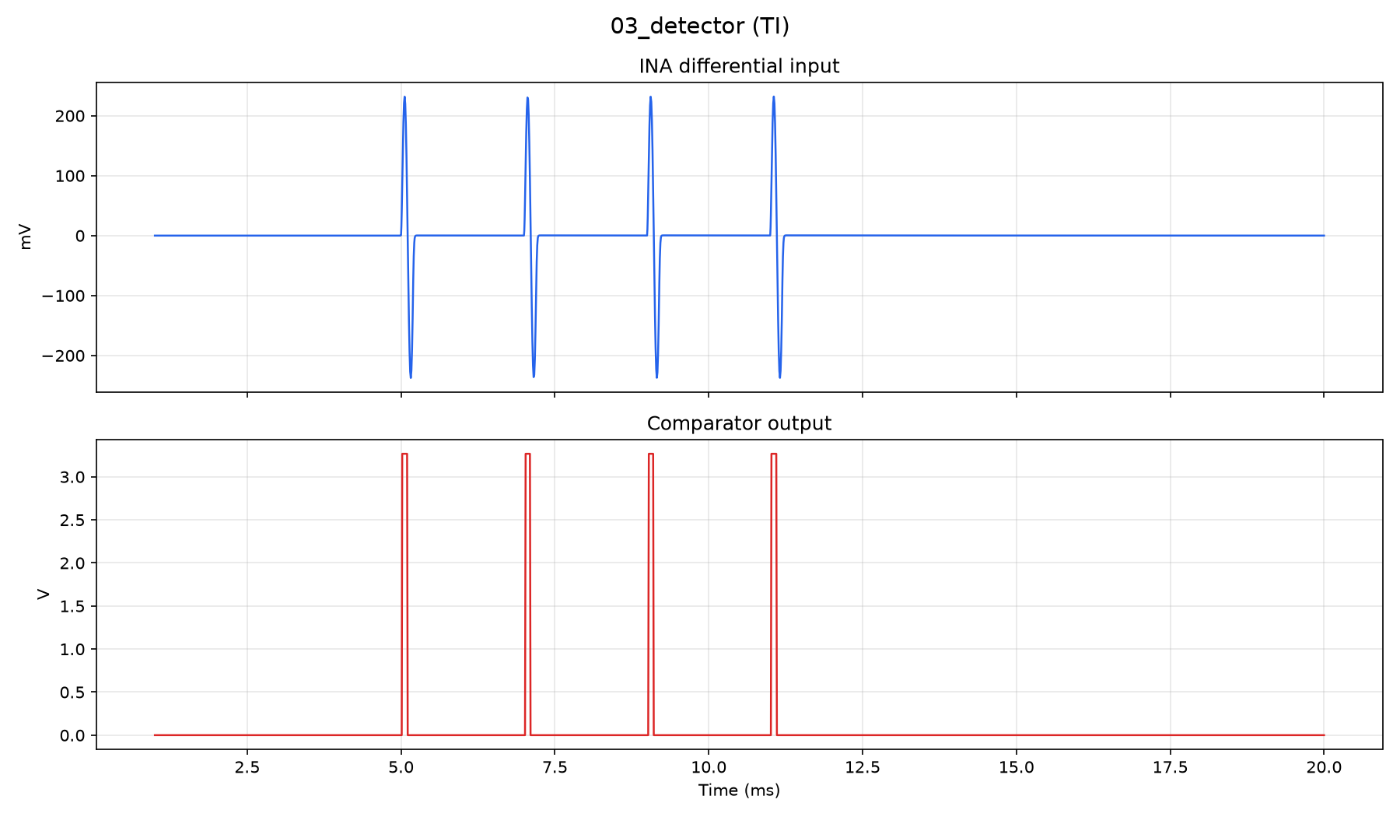
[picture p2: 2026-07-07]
outputs_probe/noc5_470p_rounded/stages/03_detector/03_detector_waveforms_ti.png

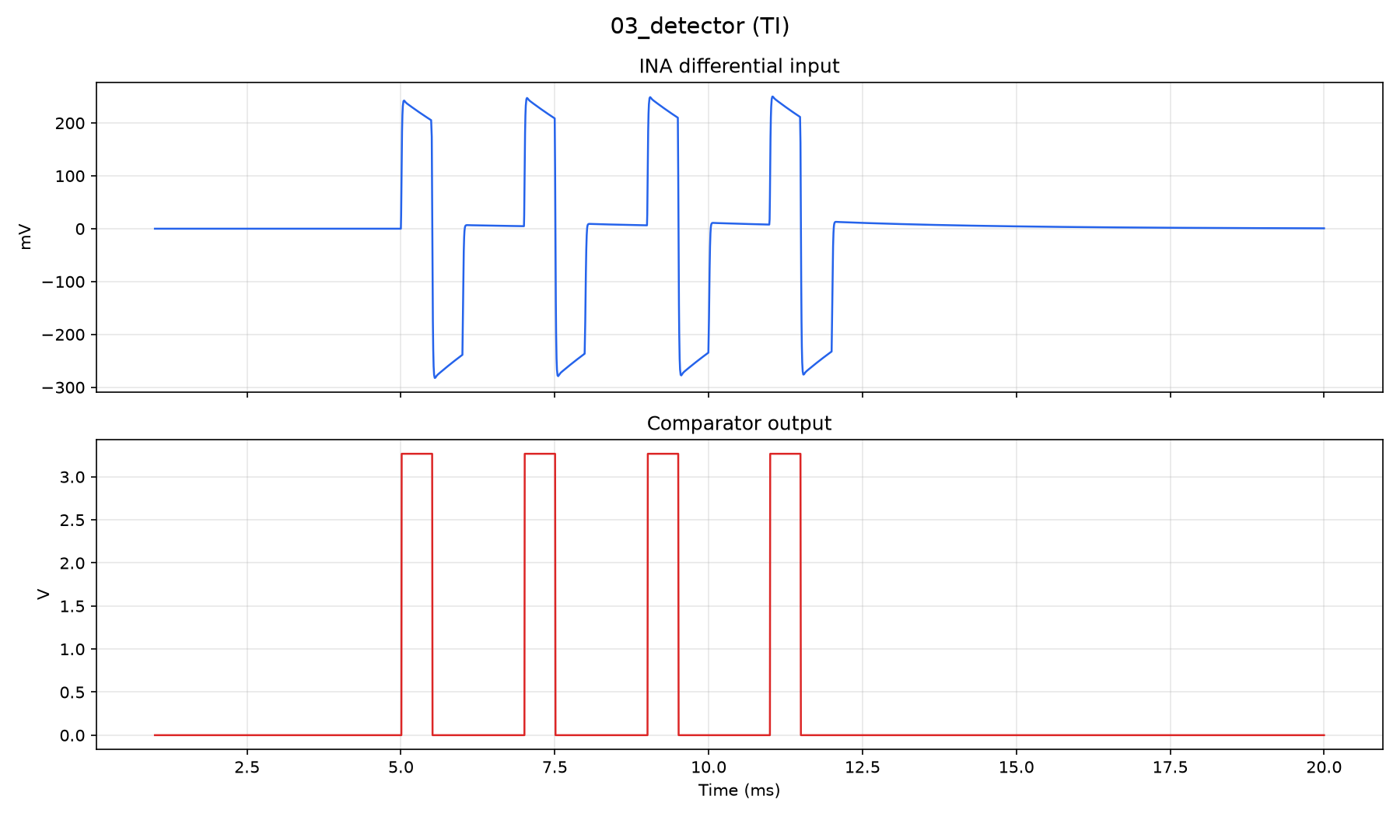
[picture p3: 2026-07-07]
outputs_probe/noc5_1f_square/stages/03_detector/03_detector_waveforms_ti.png

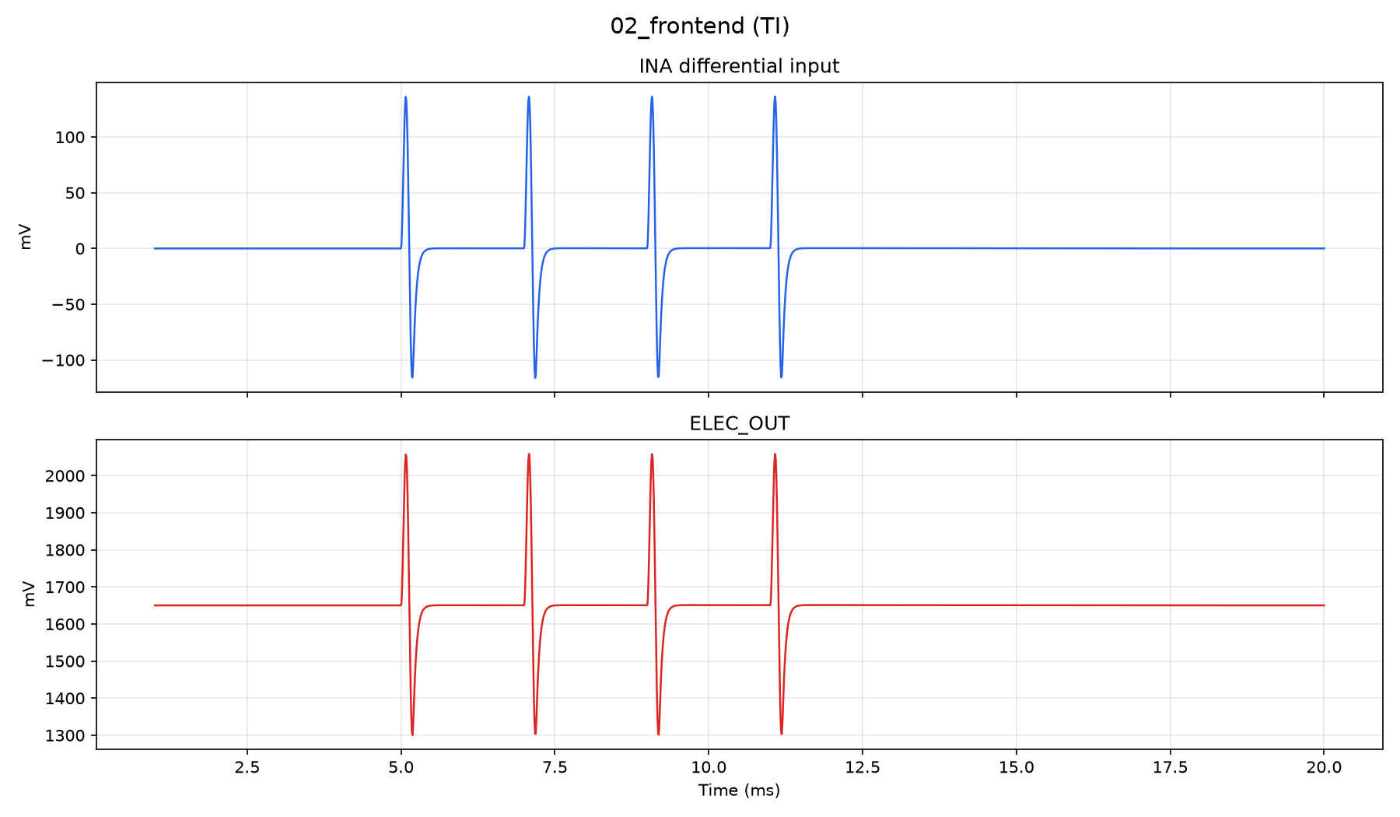
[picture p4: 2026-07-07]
outputs_probe/bench_s02_330p/stages/02_frontend/02_frontend_waveforms_ti.png

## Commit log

2026-07-04 Add ngspice INA333 simulation framework with Python visualization.
    Scaffold EOD pulse train generation, batch ngspice CLI runs, raw parsing,
    and matplotlib/plotly plots for ideal and TI macromodel benches.
2026-07-04 Add staged EOD detector simulation, tuning GUI, and KiCad front-end.
    Incremental ngspice stages from passives through full detector, with Dash
    tuning, optional LF water-offset stimulus, parameterized INA input network,
    and TI macromodel benches as the default for realistic validation.
    [EOD_Detector_v3-1.kicad_sch]
2026-07-05 Replace vendor MCP6561 with behavioral comparator for reliable detector sims.
    The TI macromodel's ESD diodes caused non-deterministic convergence when
    cascaded with INA333; stage 03 now uses a deterministic behavioral
    comparator with physical R5 hysteresis. Adds post-run validation, ngspice
    timeout, integration tests, GUI stimulus overlay fixes, component value
    recommendations, and ELECTRODES.md design notes for a future tank model.
2026-07-05 Add electrode mismatch modeling, GUI presets, and stability guidance.
    Introduce per-electrode Rs with a mismatch knob, recommended component defaults (G≈3, C4=47p, C5=470p), and board presets for stock vs ideal vs no-C4 configs; document C4/C5 oscillation findings and future hardware direction in FUTURE.md.
2026-07-05 remaining images
    [input_diff.txt]
2026-07-06 Add recorded EOD pulse shape from lab CSV captures.
    Enables --waveform recorded with baseline correction, central pulse extraction, and asymmetric scaling so real fish waveforms can drive simulations and the tuning GUI.
    [EOD_row_02.csv]
2026-07-06 Recommend removing C5 and set Ideal v3 default to 1 fF.
    Bench-confirmed oscillation at ELEC_OUT with stock C5; docs now recommend
    deleting C5 (or ≤470 pF), and the simulator defaults model C5 as removed.
2026-07-07 output probe
    [input_diff.txt]
